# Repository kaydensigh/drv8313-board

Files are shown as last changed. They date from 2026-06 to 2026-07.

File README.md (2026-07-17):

# DRV8313 Board

An open-hardware **3-phase motor driver module** built around the Texas Instruments
[**DRV8313**](https://www.ti.com/lit/ds/symlink/drv8313.pdf) (three half-bridges, 8–60 V).
It drives BLDC/PMSM motors (3-PWM / FOC, e.g. with [SimpleFOC](https://simplefoc.com)),
and — because the three half-bridges and their enables are broken out independently —
also brushed-DC motors, solenoids, and 6-step/trapezoidal loads.

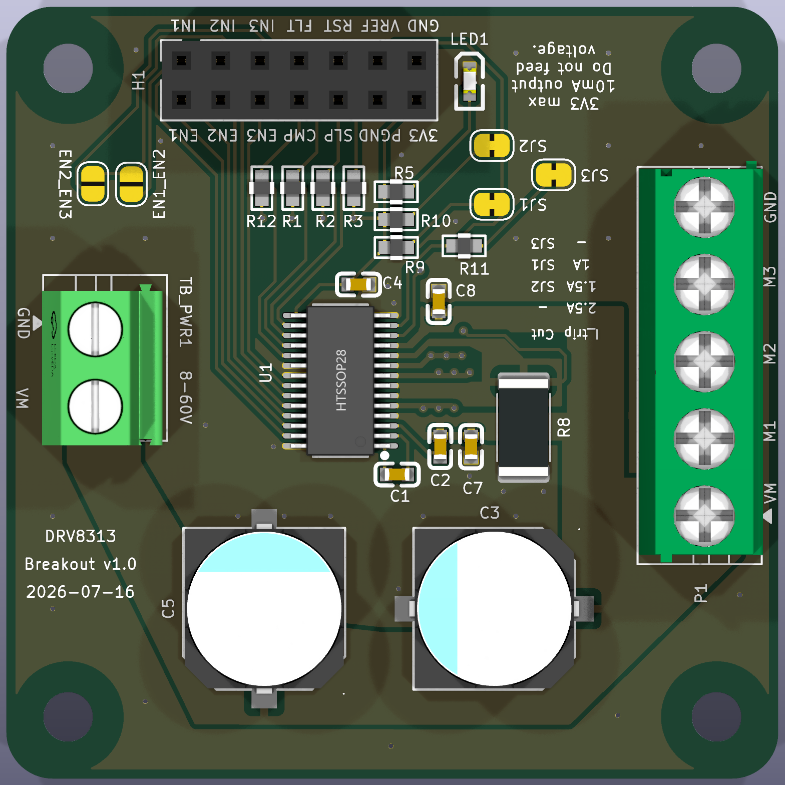
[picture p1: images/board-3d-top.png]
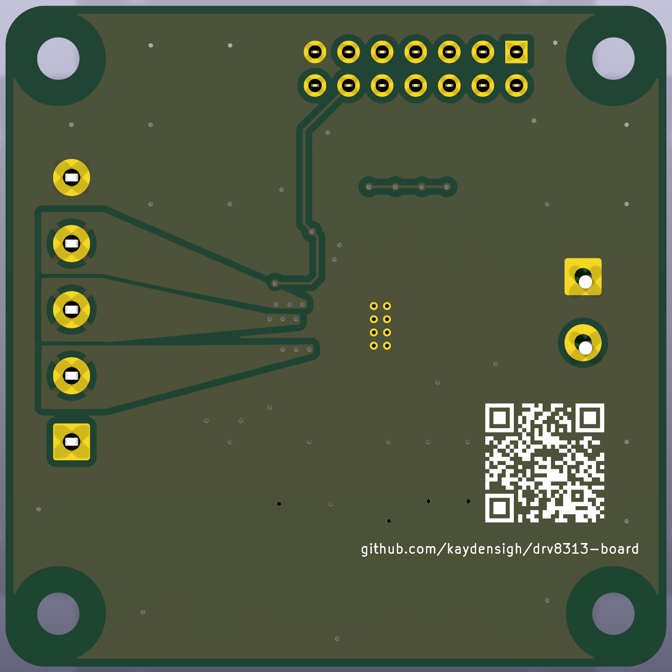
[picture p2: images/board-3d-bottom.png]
 

> Derived from the [SimpleFOCMini](https://github.com/simplefoc/SimpleFOCMini) board
> ([EasyEDA source](https://easyeda.com/the.skuric/simplefocmini)) and re-engineered for
> the DRV8313's full voltage range. It has since diverged substantially from the original
> (higher voltage, larger 4-layer board, on-board current limit, independent half-bridge
> enables), hence the separate project.

## Specifications

| | |
| --- | --- |
| Driver | DRV8313PWPR (HTSSOP-28, exposed thermal pad) |
| Supply voltage | **8–60 V** |
| Continuous current | **~1.5 A / phase** (1 oz copper, Tj ≤ 125 °C; ~2 A with airflow). The datasheet's 2.5 A/phase is a *peak* rating. |
| Logic level | 3.3 V (DRV8313 on-chip `V3P3OUT` regulator; no separate LDO). The `3.3V` header pin is an **output only — max 10 mA**; never drive it from the host. |
| Board | **50 × 50 mm**, 4-layer (Top / GND / GND / Bottom, 1 oz) |
| Control | 3× IN (PWM) + 3× independent EN (solder jumpers gang them for 3-PWM/FOC); nRESET / nSLEEP / nFAULT |
| Current limit | On-board comparator (50 mΩ shunt + jumper-set reference divider); raises `nCOMPO` flag on the header — host acts on it, no automatic shutdown |
| Connectors | 2×7 control header, 5-pos motor/VM terminal block, 2-pos power terminal block |

### Features beyond the original SimpleFOCMini

- **8–60 V** input (vs. 8–24 V) on a 4-layer board with inner ground planes.
- **On-board over-current detection** using the DRV8313's internal comparator (`COMPP`/`COMPN`):
  a 50 mΩ low-side shunt and a 3.3 V reference divider, with three solder jumpers (bridged by
  default) setting the trip point — all bridged ≈ 2.5 A, cut `SJ1` ≈ 1.05 A, cut `SJ2` ≈ 1.5 A,
  cut `SJ3` disables it. The comparator raises the open-drain `nCOMPO` flag on the header; it
  does not shut the bridge down by itself.
- **Independent half-bridge enables** (`EN1`/`EN2`/`EN3`, each brought out on the header) so the
  board can run brushed-DC / solenoid / 6-step loads. Two **solder jumpers on the board**
  (`EN1_EN2`, `EN2_EN3` — open by default) gang the three enables back together for the
  original 3-PWM/FOC drive: bridge both and a single host pin drives all three, with no wiring
  at the header.

## Renders

| Schematic | PCB (top) | PCB (bottom) |
| --- | --- | --- |
|  |  |  |

## Repository layout

| Path | Contents |
| --- | --- |
| [`KiCad/project/`](./KiCad/project/) | KiCad 10 source — schematic, PCB, project, and the `drv8313-board` project library (`.pretty` footprints + `.kicad_sym` symbols) |
| [`manufacturing/`](./manufacturing/) | Fabrication outputs: [`gerbers/`](./manufacturing/gerbers/) (Gerber + Excellon drill), [BOM](./manufacturing/drv8313-board-BOM.csv), [pick-and-place CPL](./manufacturing/drv8313-board-CPL.csv), and a [STEP](./manufacturing/drv8313-board.step) 3D model |
| [`docs/`](./docs/) | [`datasheets/`](./docs/datasheets/) — the DRV8313 datasheet (authoritative part reference) |
| [`tools/`](./tools/) | Headless helper scripts — JLCPCB part search, manufacturing-file regeneration, silk version bump ([`tools/README.md`](./tools/README.md)) |
| [`images/`](./images/) | Renders used above |

The design is maintained **only** in KiCad now; the original Altium / EasyEDA / PDF exports
have been removed. The manufacturing files are regenerated from the KiCad project with
[`tools/build_manufacturing.py`](./tools/build_manufacturing.py) (a `kicad-cli` wrapper).

## Bill of materials

The full BOM (with footprints) is [`manufacturing/drv8313-board-BOM.csv`](./manufacturing/drv8313-board-BOM.csv).
Each MPN below links to its LCSC product page; **Library** is the JLCPCB part class —
**Basic** and **Preferred** are fee-free, **Extended** parts each add a one-time setup fee.

| Designator | Value | Qty | MPN | Unit price | Library |
| --- | --- | --- | --- | --- | --- |
| C1 | 10nF 100V | 1 | [CL10B103KC8NNNC](https://www.lcsc.com/product-detail/multilayer-ceramic-capacitors-mlcc-smd-smt_samsung-electro-mechanics-cl10b103kc8nnnc_C84709.html) | $0.0058 | Extended |
| C2 | 100nF 16V | 1 | [CC0603KRX7R9BB104](https://www.lcsc.com/product-detail/multilayer-ceramic-capacitors-mlcc-smd-smt_yageo-cc0603krx7r9bb104_C14663.html) | $0.0194 | Basic |
| C3,C5 | 47uF 100V | 2 | [RVT2A470M1010](https://www.lcsc.com/product-detail/aluminum-electrolytic-capacitors-smd_honor-elec-rvt2a470m1010_C87862.html) | $0.1206 | Extended |
| C4 | 470nF | 1 | [CL10B474KA8NNNC](https://www.lcsc.com/product-detail/multilayer-ceramic-capacitors-mlcc-smd-smt_samsung-electro-mechanics-cl10b474ka8nnnc_C1623.html) | $0.0254 | Basic |
| C7,C8 | 100nF 100V | 2 | [CL10B104KC8NNNC](https://www.lcsc.com/product-detail/multilayer-ceramic-capacitors-mlcc-smd-smt_samsung-electro-mechanics-cl10b104kc8nnnc_C15725.html) | $0.0297 | Extended |
| H1 | PinHeader 2x7 2.54mm | 1 | [2.54-2\*7P Female](https://www.lcsc.com/product-detail/female-headers_boomele-boom-precision-elec-2-54-2-7p_C38844.html) | $0.1101 | Extended |
| LED1 | Yellow | 1 | [NCD0603Y2](https://www.lcsc.com/product-detail/led-indication-discrete_foshan-nationstar-optoelectronics-ncd0603y2_C89811.html) | $0.0194 | Preferred |
| P1 | TerminalBlock 5P 5.0mm | 1 | [DB126V-5.0-5P-GN-P](https://www.lcsc.com/product-detail/screw-terminal-blocks_dorabo-db126v-5-0-5p-gn-p_C2835160.html) | $0.2395 | Extended |
| R1-R3,R12 | 10kΩ | 4 | [0603WAF1002T5E](https://www.lcsc.com/product-detail/chip-resistor-surface-mount_uni-royal-uniroyal-elec-0603waf1002t5e_C25804.html) | $0.0078 | Basic |
| R5,R11 | 1kΩ | 2 | [0603WAF1001T5E](https://www.lcsc.com/product-detail/chip-resistor-surface-mount_uni-royal-uniroyal-elec-0603waf1001t5e_C21190.html) | $0.0024 | Basic |
| R8 | 50mΩ | 1 | [HoJLR2512-3W-50mR-1%](https://www.lcsc.com/product-detail/current-sense-resistors-shunt-resistors_milliohm-hojlr2512-3w-50mr-1_C2903475.html) | $0.0676 | Extended |
| R9 | 43kΩ | 1 | [0603WAF4302T5E](https://www.lcsc.com/product-detail/chip-resistor-surface-mount_uni-royal-uniroyal-elec-0603waf4302t5e_C23172.html) | $0.0076 | Preferred |
| R10 | 62kΩ | 1 | [0603WAF6202T5E](https://www.lcsc.com/product-detail/chip-resistor-surface-mount_uni-royal-uniroyal-elec-0603waf6202t5e_C23221.html) | $0.0092 | Preferred |
| TB_PWR1 | TerminalBlock 2P 5.0mm | 1 | [DB126V-5.0-2P-GN-P](https://www.lcsc.com/product-detail/screw-terminal-blocks_dorabo-db126v-5-0-2p-gn-p_C395849.html) | $0.0876 | Extended |
| U1 | DRV8313PWPR | 1 | [DRV8313PWPR](https://www.lcsc.com/product-detail/brushless-dc-bldc-motor-driver_texas-instruments-drv8313pwpr_C92482.html) | $1.4973 | Extended |

**Component cost ≈ $2.43/board in volume** (unit prices at JLCPCB's 100-piece tier, 2026-07-17;
U1 dominates). 8 parts are **Extended** (one-time setup fee each); the rest are fee-free.

**A small batch of 10 boards ≈ $55.53 in parts (~$5.55/board)**: $31.53 of components (JLCPCB
per-part assembly minimums + attrition applied) plus 8 × $3 Extended-part setup fees ($24). The
fixed fees amortise over larger runs. Excludes PCB fabrication, assembly labour and shipping.

Regenerate these from live prices with [`tools/gen_readme_bom.py`](./tools/gen_readme_bom.py)
(`--batch N` for a different run size); verify live stock with
[`tools/check_bom.py`](./tools/check_bom.py).

## Ordering

The board is designed to be fabricated and assembled at [JLCPCB](https://jlcpcb.com):

1. Upload `manufacturing/gerbers/` (zipped) for fabrication — 4-layer, 1 oz.
2. Use `manufacturing/drv8313-board-BOM.csv` and `manufacturing/drv8313-board-CPL.csv`
   for assembly. Every line carries an LCSC part number. Most parts are **fee-free** on
   JLCPCB — Basic or Preferred, no per-part setup fee — including the 43 k/62 k divider
   resistors (Preferred). The unavoidable **Extended** parts are the DRV8313 itself, the
   10 nF/100 V, 100 nF/100 V and 47 µF/100 V capacitors, the 50 mΩ current-sense shunt, and
   the three connectors. The connectors — `H1` (2×7 header), `P1` and `TB_PWR1` (5 mm screw terminal
   blocks) — are **through-hole**: order them via JLCPCB's through-hole assembly add-on or
   solder them by hand. Re-verify live stock before ordering — `tools/jlc_search.py` checks
   live stock/price (note: the 10 kΩ Basic resistor occasionally reads out of stock).

> **Status:** functional design — schematic and PCB are complete, fully routed, and both
> **DRC- and ERC-clean (0 violations)**. Not yet fabricated/validated in hardware. Review
> before ordering. Re-verify any time with
> [`tools/check_design.py`](./tools/check_design.py) (DRC + connectivity + ERC) and
> [`tools/check_bom.py`](./tools/check_bom.py) (live JLCPCB part stock).

## License

See [`LICENSE`](./LICENSE). This project inherits from the open-source SimpleFOCMini; please
also credit the original authors.

## Credits

Based on [**SimpleFOCMini**](https://github.com/simplefoc/SimpleFOCMini) by the
[SimpleFOC](https://simplefoc.com) project (Antun Skuric et al.).

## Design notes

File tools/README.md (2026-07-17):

# tools/

Headless helper scripts for the DRV8313 board. They run against the KiCad
project under [`../KiCad/project/`](../KiCad/project/) and need only KiCad 10's
bundled Python / `kicad-cli` — no GUI. On Windows:

```powershell
$PY = "C:\Program Files\KiCad\10.0\bin\python.exe"
& $PY tools\<script>.py ...
```

`jlc_search.py` is stdlib-only (any Python 3); the other two need KiCad's
`pcbnew` / `kicad-cli`, so use the bundled interpreter above.

---

## `jlc_search.py` — pick JLCPCB / LCSC parts

Queries the **live** JLCPCB parts API and ranks matches the way this BOM is
sourced: **fee-free first**, then **cheapest unit price**, in stock only.
JLCPCB charges a per-part setup fee only for plain **Extended** parts — **Basic**
and **Preferred** parts incur no extra charge — so those rank first.

```powershell
& $PY tools\jlc_search.py "10kohm 0603 1%"            # ranked table
& $PY tools\jlc_search.py "100nF 0603 X7R" --fee-free  # Basic OR Preferred only
& $PY tools\jlc_search.py "47uF 100V" --fee-free       # confirm no fee-free option exists
& $PY tools\jlc_search.py C92482                       # look up one part by LCSC id
```

Flags: `--fee-free` / `--basic` / `--preferred` apply a **server-side** library
filter — the reliable way to surface no-fee parts, since a plain keyword search
ranks cheap Extended parts first and buries the Basic/Preferred ones. Also
`--package 0603`, `--attr 1%` (substring in the description), `--qty N`
(unit-price tier, default 50), `--min-stock N`, `--pages N`, `--json`.

> The [yaqwsx/jlcparts](https://yaqwsx.github.io/jlcparts) browser mirrors the
> same JLC catalogue into a static database — handy to browse, heavier to
> script against. This script hits the source API live, so stock/price are
> current and no catalogue download is needed.

## `build_manufacturing.py` — regenerate all fabrication outputs

Rebuilds the JLCPCB fab package **and** the README visuals from the project, so
a design change never leaves stale outputs behind.

```powershell
& $PY tools\build_manufacturing.py            # everything
& $PY tools\build_manufacturing.py --fab      # gerbers / drill / zip / CPL / BOM / STEP only
& $PY tools\build_manufacturing.py --images   # 3D renders + SVGs only
```

Produces, under [`../manufacturing/`](../manufacturing/): `gerbers/` (Protel
extensions) + Excellon drill, `drv8313-board-gerbers.zip` (upload-ready),
`drv8313-board-CPL.csv` (pick-and-place), `drv8313-board-BOM.csv` (grouped, with
MPN + LCSC), `drv8313-board.step`; and under [`../images/`](../images/):
`board-3d-{top,bottom}.png` (straight top-down / bottom-up 3D renders),
`schematic.svg`, and `pcb-{top,bottom}.svg` (2D copper + silk plots on a dark
background — KiCad's SVG export is always transparent, so a background rect is
injected for legibility).

It keeps a **defensive snapshot of `project.kicad_pro`** — a no-op on the current
canonical file (kicad-cli leaves it byte-identical; verified), restored with a
warning only if a future KiCad version re-normalises it. It only *generates*; it
does not run DRC/ERC. Override the toolchain with `$env:KICAD_CLI`.

## `set_silk_version.py` — bump the silkscreen version stamp

```powershell
& $PY tools\set_silk_version.py --show        # current: Breakout v1.0 / 2026-07-16
& $PY tools\set_silk_version.py 2.1           # -> Breakout v2.1
& $PY tools\set_silk_version.py 2.1 --date 2026-09-01   # also stamp a date
& $PY tools\set_silk_version.py 2.1 --date auto         # ... or today
```

Rewrites the `vN.M` token wherever it appears on a silk layer (preserving a
surrounding label like `Breakout `) plus the **ISO `YYYY-MM-DD`** date stamp —
the format this board's silk uses. `--date` takes an ISO date or `auto`
(today), and rejects anything that isn't a real calendar date. Silk **text
only** — copper/geometry untouched; does not edit README/docs version
references. After bumping, regenerate the board images with
`build_manufacturing.py`.

---

## `render_datasheet.py` — render datasheet PDF pages to images

Text extraction loses a datasheet's **figures** — and the reference schematic
you wire from *is* a figure. Render the page, look at the image, and wire from
what the figure shows; never wire from prose text-extraction alone. (The
DRV8313 datasheet's §8.2.2.2.1 prose contradicts its own Figure 12 on the
comparator pins — following the text wires COMPP/COMPN backwards.)

```powershell
& $PY tools\render_datasheet.py docs\datasheets\drv8313.pdf --toc   # find the right pages
& $PY tools\render_datasheet.py docs\datasheets\drv8313.pdf 12      # §7.3.4 comparator figure
& $PY tools\render_datasheet.py some.pdf 13-15,23 --dpi 200 --out-dir _scratch_ds
```

Uses PyMuPDF (`fitz`), installed in KiCad's bundled Python. PNGs land in
`%TEMP%\datasheet-render\<stem>\` by default; paths are printed. Page numbers
are 1-based PDF pages. `--toc` prints the bookmark tree so you can jump
straight to "Application and Implementation" or a pin-function table.

## `render_sch.py` — render the schematic for visual inspection

ERC and the netlist prove the schematic is *correct*; only looking at a render
proves it is *readable*. Render + inspect after every placement/label edit —
the visual analogue of running DRC after every copper edit.

```powershell
& $PY tools\render_sch.py                          # whole sheet -> %TEMP%\kicad-render\
& $PY tools\render_sch.py --density 300            # zoom to read labels
& $PY tools\render_sch.py --crop 800x600+200+150   # pixel crop of one region
```

Needs `kicad-cli` + ImageMagick `magick` (both installed); any Python 3 works.

## `sch_lint.py` — schematic readability lint (numeric oracle)

Scores the visual defects blind editing introduces: overlapping value/ref
text, text through symbol bodies or across wires, wire crossings, stacked
symbols, off-grid endpoints. Iterate edits against this score the way copper
edits iterate against DRC, then confirm with `render_sch.py`. Geometry is
heuristic (text boxes estimated from character counts, bodies from pin
extents) — findings are pointers to check in a render, and the total is a
score to drive down, not ground truth.

```powershell
& $PY tools\sch_lint.py                    # report + total
& $PY tools\sch_lint.py --verbose --json   # every finding, machine-readable
& $PY tools\sch_lint.py --fail-over 10     # CI gate on the issue count
```

Needs kicad-skip, so run with KiCad's bundled Python. Informational findings
(e.g. a power symbol placed directly on a component pin — electrically fine
but the part looks unwired) are reported but not counted.

---

## `check_design.py` — verify DRC / connectivity / ERC

Runs the checks the board is validated against and prints a PASS/FAIL summary;
**exits nonzero if any hard check fails** (drop into CI or a pre-commit hook).

```powershell
& $PY tools\check_design.py
```

| Check | Tool | Gate |
| --- | --- | --- |
| DRC (error severity) | `kicad-cli pcb drc --severity-error --refill-zones` | **hard** — must be 0 (authoritative: incl. unconnected, clearance, shorts) |
| Connectivity (all nets) | KiCadRoutingTools `check_connected.py` | advisory cross-check |
| Clearance / shorts | KiCadRoutingTools `check_drc.py` | advisory cross-check |
| ERC | `kicad-cli sch erc` | tripwire — flagged if `!= 0` |

kicad-cli's error-severity DRC is the authoritative connectivity/clearance/short
gate (its ratsnest understands zone fills + through-pad + off-anchor pad entries).
The two KRT checks are **advisory** only — their endpoint-graph model emits false
positives on perfectly-connected manual routing (a track ending inside a pad but
not at its anchor, or tracks meeting *through* a large pad), so they print but
never fail the build. The ERC baseline (0 = fully clean) and the DRC
*warning*-severity items are EasyEDA-import cosmetic artifacts (documented in
CLAUDE.md), so ERC is a **regression tripwire**, not a gate. Keeps a defensive
`project.kicad_pro` snapshot (a no-op today — kicad-cli leaves the canonical file
untouched).
Needs [KiCadRoutingTools](https://github.com/drandyhaas/KiCadRoutingTools) at
`../KiCadRoutingTools` for the connectivity/clearance checks (override with
`$env:KRT_DIR` / `$env:KRT_PYTHON`); if absent, those two are skipped and the
gate falls back to DRC + ERC.

## `check_bom.py` — verify BOM stock + fee status (live)

Looks up every LCSC part in `manufacturing/drv8313-board-BOM.csv` on JLCPCB and
reports stock, Basic/Preferred/Extended (fee status) and price; **flags
out-of-stock / discontinued parts and exits nonzero** if any part is out of
stock — the exact failures that bit this BOM (LED1 went out of stock; the 10 kΩ
Basic part periodically reads 0). Run it before ordering.

```powershell
& $PY tools\check_bom.py                  # fails on any 0-stock part
& $PY tools\check_bom.py --min-stock 100  # also fail on low stock
& $PY tools\check_bom.py --bom other.csv
```

Reuses `jlc_search.py`. Also tallies the unique Extended parts (= one JLCPCB
setup fee each). *(As of this writing it reports the 10 kΩ `C25804` out of stock
— a transient JLC condition on its most-used Basic resistor; re-run before
ordering.)*

## `gen_readme_bom.py` — Markdown BOM table for the README

Emits the README's Bill-of-materials table from the BOM CSV plus **live** JLCPCB
prices: `Designator | Value | Qty | MPN | Unit price | Library`, each MPN linked
to its LCSC page, followed by an estimated per-board component-cost total.

```powershell
& $PY tools\gen_readme_bom.py                  # paste output into README.md
& $PY tools\gen_readme_bom.py --price-qty 10   # quote a different price tier
```

Prices are live, so the table is a dated snapshot — re-run to refresh. Reuses
`jlc_search.py`.

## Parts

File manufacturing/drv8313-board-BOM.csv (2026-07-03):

Designator | Value | Footprint | Qty | MPN | LCSC
C1 | 10nF 100V | drv8313-board:C0603 | 1 | CL10B103KC8NNNC | C84709
C2 | 100nF 16V | drv8313-board:C0603 | 1 | CC0603KRX7R9BB104 | C14663
C3,C5 | 47uF 100V | drv8313-board:CAP-SMD_BD10.0-L10.3-W10.3-FD-LS11.0 | 2 | RVT2A470M1010 | C87862
C4 | 470nF | drv8313-board:C0603 | 1 | CL10B474KA8NNNC | C1623
C7,C8 | 100nF 100V | drv8313-board:C0603 | 2 | CL10B104KC8NNNC | C15725
H1 | PinHeader 2x7 2.54mm | Connector_PinSocket_2.54mm:PinSocket_2x07_P2.54mm_Vertical | 1 | 2.54-2*7P Female | C38844
LED1 | Yellow | drv8313-board:LED0603-R-RD | 1 | NCD0603Y2 | C89811
P1 | TerminalBlock 5P 5.0mm | TerminalBlock:TerminalBlock_MaiXu_MX126-5.0-05P_1x05_P5.00mm | 1 | DB126V-5.0-5P-GN-P | C2835160
R1-R3,R12 | 10kΩ | drv8313-board:R0603 | 4 | 0603WAF1002T5E | C25804
R5,R11 | 1kΩ | drv8313-board:R0603 | 2 | 0603WAF1001T5E | C21190
R8 | 50mΩ | Resistor_SMD:R_2512_6332Metric | 1 | HoJLR2512-3W-50mR-1% | C2903475
R9 | 43kΩ | drv8313-board:R0603 | 1 | 0603WAF4302T5E | C23172
R10 | 62kΩ | drv8313-board:R0603 | 1 | 0603WAF6202T5E | C23221
TB_PWR1 | TerminalBlock 2P 5.0mm | TerminalBlock:TerminalBlock_MaiXu_MX126-5.0-02P_1x02_P5.00mm | 1 | DB126V-5.0-2P-GN-P | C395849
U1 | DRV8313PWPR | drv8313-board:HTSSOP-28_L9.8-W4.5-P0.65-LS6.6-BL-EP | 1 | DRV8313PWPR | C92482

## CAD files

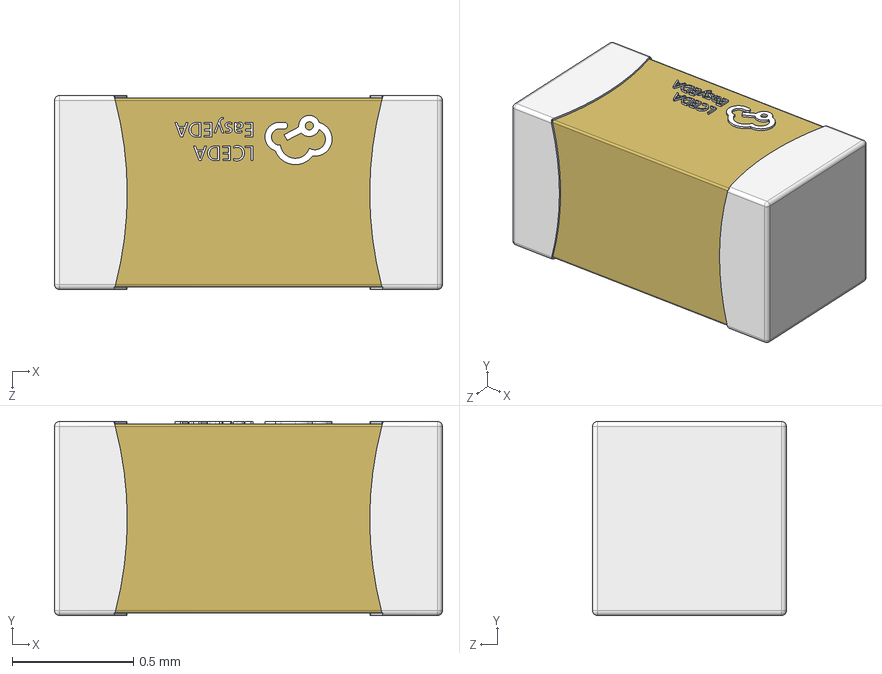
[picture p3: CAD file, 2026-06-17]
KiCad/project/EASYEDA_MODELS/C0603_L1.6-W0.8-H0.8.step
1.60 x 0.8 x 0.8 mm

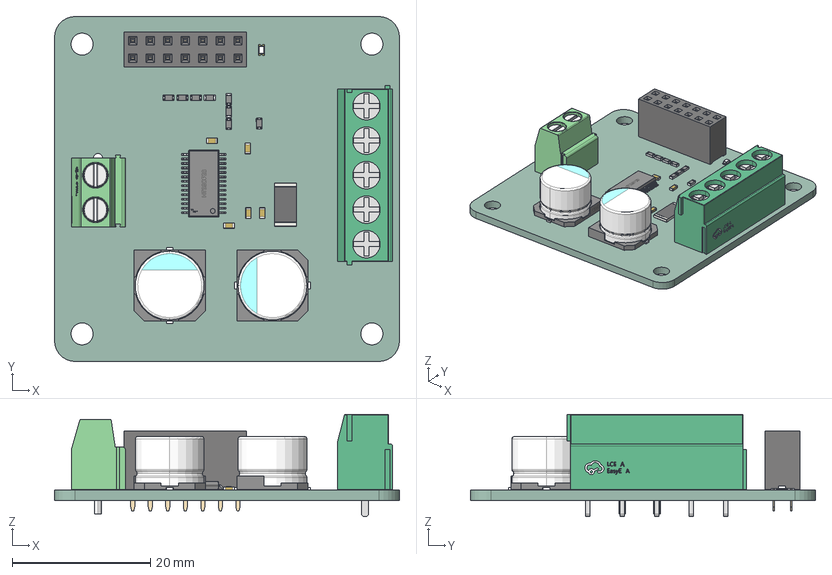
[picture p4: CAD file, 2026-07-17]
manufacturing/drv8313-board.step
50.0 x 50.0 x 14.8 mm
R0603 x 8
C0603_L1.6-W0.8-H0.8 x 5
CONN-TH_DB5.00-LI-2P-126
CONN-TH_5P-P5.00-L8.0-W25.0
HTSSOP-28_L9.7-W4.4-H1.2-LS6.4-P0.65
R_2512_6332Metric
PinSocket_2x07_P2.54mm_Vertical
CAP-SMD_BD10.0-L10.3-W10.3-FD-LS11.0 x 2
LED0603-RD-YELLOW
project_PCB

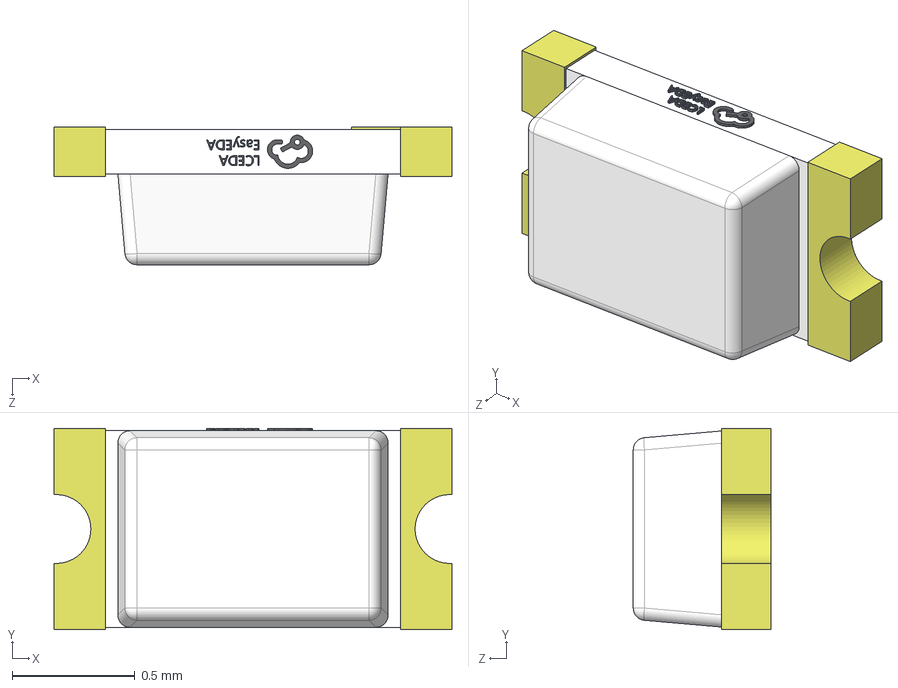
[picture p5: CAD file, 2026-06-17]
KiCad/project/EASYEDA_MODELS/LED0603-RD-YELLOW.step
1.62 x 0.82 x 0.56 mm

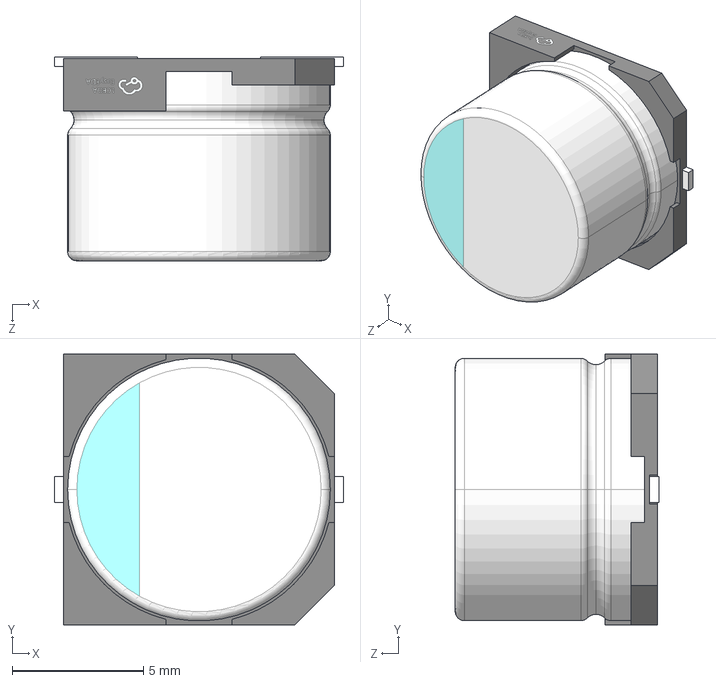
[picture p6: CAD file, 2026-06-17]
KiCad/project/EASYEDA_MODELS/CAP-SMD_BD10.0-L10.3-W10.3-FD-LS11.0.step
11.0 x 10.3 x 7.75 mm

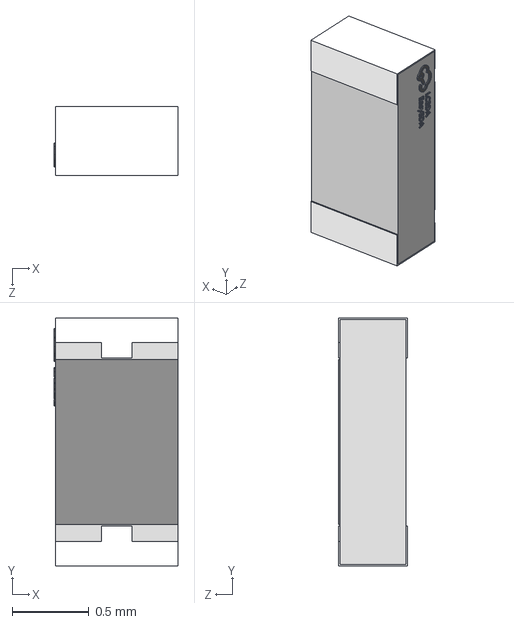
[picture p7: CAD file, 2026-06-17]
KiCad/project/EASYEDA_MODELS/R0603.step
0.81 x 1.62 x 0.45 mm

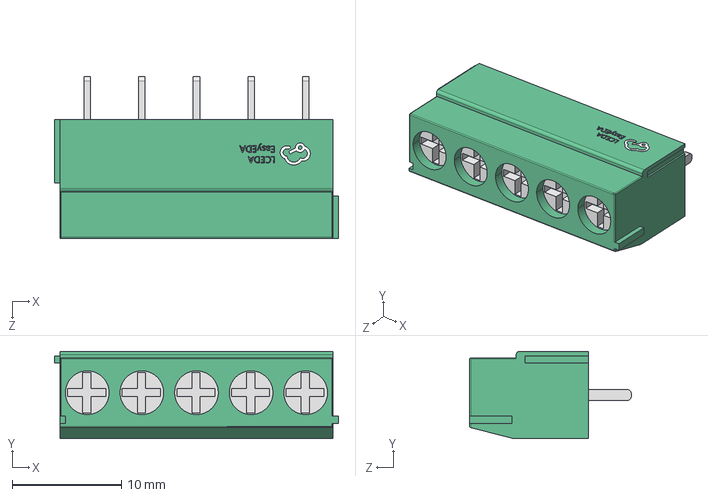
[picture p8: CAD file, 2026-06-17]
KiCad/project/EASYEDA_MODELS/CONN-TH_5P-P5.00-L8.0-W25.0.step
26.0 x 8.00 x 14.8 mm

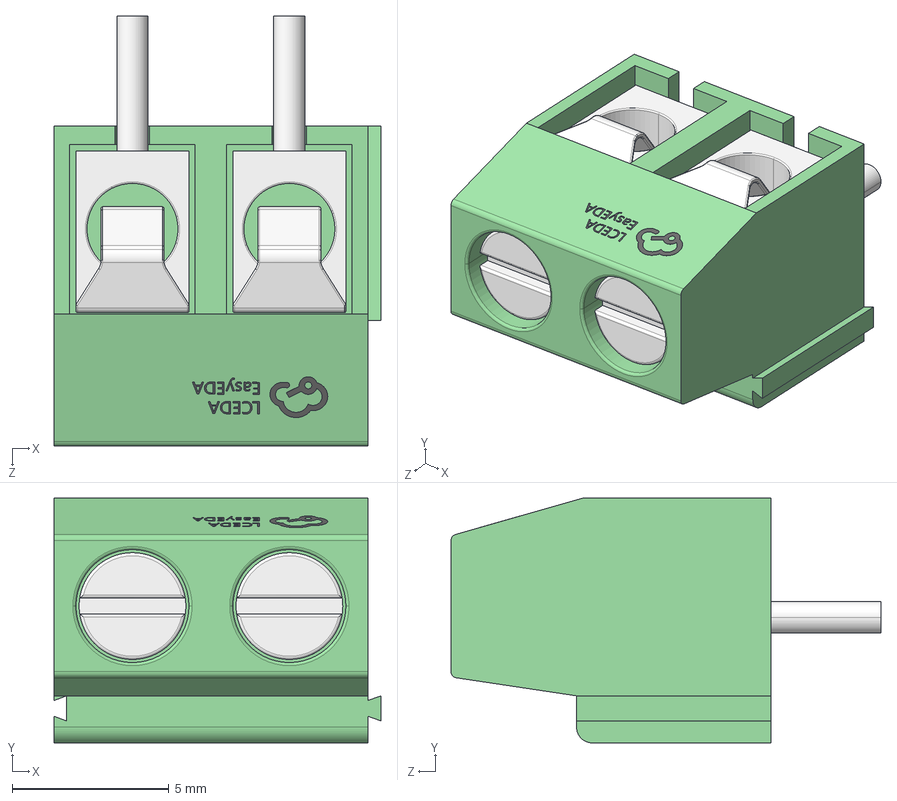
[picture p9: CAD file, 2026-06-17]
KiCad/project/EASYEDA_MODELS/CONN-TH_DB5.00-LI-2P-126.step
10.4 x 7.80 x 13.7 mm

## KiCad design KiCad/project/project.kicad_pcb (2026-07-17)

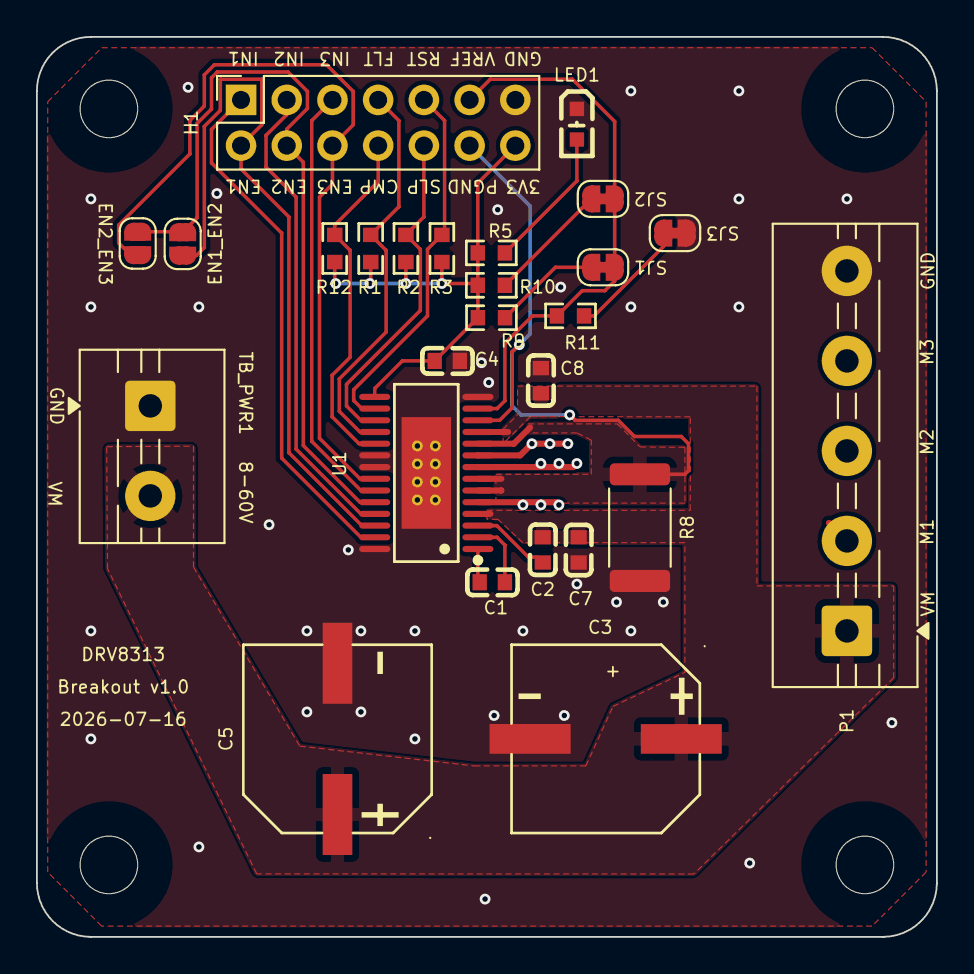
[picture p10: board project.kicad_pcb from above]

Board: 4 copper layers, 50.0 x 50.0 mm, 30 parts (0 on the bottom side), 25 nets.

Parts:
C1: 10nF 100V; C0603
C2: 100nF 16V; C0603
C3, C5: 47uF 100V; CAP-SMD_BD10.0-L10.3-W10.3-FD-LS11.0
C4: 470nF; C0603
C7, C8: 100nF 100V; C0603
EN1_EN2, EN2_EN3: SolderJumper_2_Open; SolderJumper-2_P1.3mm_Open_RoundedPad1.0x1.5mm
H1: PinHeader 2x7 2.54mm; PinSocket_2x07_P2.54mm_Vertical
LED1: Yellow; LED0603-R-RD
MH1, MH2, MH3, MH4: MountingHole_3.2mm_M3
P1: TerminalBlock 5P 5.0mm; TerminalBlock_MaiXu_MX126-5.0-05P_1x05_P5.00mm
R1, R2, R3, R12: 10kΩ; R0603
R5, R11: 1kΩ; R0603
R8: 50mΩ; R_2512_6332Metric
R9: 43kΩ; R0603
R10: 62kΩ; R0603
SJ1, SJ2, SJ3: JMP; SolderJumper-2_P1.3mm_Bridged_RoundedPad1.0x1.5mm
TB_PWR1: TerminalBlock 2P 5.0mm; TerminalBlock_MaiXu_MX126-5.0-02P_1x02_P5.00mm
U1: DRV8313PWPR; HTSSOP-28_L9.8-W4.5-P0.65-LS6.6-BL-EP

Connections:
3.3V: C4.2, H1.14, R1.1, R2.1, R3.1, R5.1, R9.1, R10.1, R12.2, U1.15 (V3P3OUT)
EN1: EN1_EN2.1 (A), H1.2, U1.26 (EN1)
EN2: EN1_EN2.2 (B), EN2_EN3.1 (A), H1.4, U1.24 (EN2)
EN3: EN2_EN3.2 (B), H1.6, U1.22 (EN3)
GND: C3.2, C4.1, C5.2, C7.1, C8.1, H1.13, LED1.2 (C), P1.5, R8.2, SJ3.2 (B), TB_PWR1.1, U1.14 (GND), U1.20 (GND), U1.21 (NC), U1.28 (GND), U1.29 (EP)
IN1: H1.1, U1.27 (IN1)
IN2: H1.3, U1.25 (IN2)
IN3: H1.5, U1.23 (IN3)
M1: P1.2, U1.5 (OUT1)
M2: P1.3, U1.8 (OUT2)
M3: P1.4, U1.9 (OUT3)
unnamed: LED1.1 (A), R5.2
unnamed: R9.2, SJ1.1 (A)
unnamed: R10.2, SJ2.1 (A)
unnamed: R11.2, SJ3.1 (A)
unnamed: C1.2, U1.1 (CP1)
unnamed: C1.1, U1.2 (CP2)
unnamed: C2.2, U1.3 (VCP)
PGND: H1.12, R8.1, U1.6 (PGND1), U1.7 (PGND2), U1.10 (PGND3), U1.12 (COMPP)
VCC: C2.1, C3.1, C5.1, C7.2, C8.2, P1.1, TB_PWR1.2, U1.4 (VM), U1.11 (VM)
VREF: H1.11, R11.1, SJ1.2 (B), SJ2.2 (B), U1.13 (COMPN)
nCOMPO: H1.8, R12.1, U1.19 (COMPO#)
nFlt: H1.7, R1.2, U1.18 (FAULT#)
nRes: H1.9, R3.2, U1.16 (RESET#)
nSlp: H1.10, R2.2, U1.17 (SLEEP#)

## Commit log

2026-06-16 Add KiCad 10 project converted from EasyEDA source
    Imported from the EasyEDA Std design files via KiCad's importer.
    All 13 components, board outline, routing, vias, and GND/VCC copper
    pours came across. Known import artifacts (clearance/silk/parity noise,
    schematic pin-type and library associations) to be cleaned up next.
    [project.kicad_pcb, project.kicad_sch]
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2026-06-16 Configure project for 60V redesign: 4-layer stackup + Power net class
    Project-setup pass (board config only; no copper re-routed yet):
    - PCB set to 4 copper layers via pcbnew: F.Cu (TopLayer), In1.Cu (GND1),
    In2.Cu (GND2), B.Cu (BottomLayer), 1.6mm. Inner layers named to encode
    the Top/GND/GND/Bottom intent; pour GND zones on them during layout.
    - Add a Power net class (0.8mm track ~= 2A headroom on 1oz, 0.3mm clearance
    for 60V, 0.8/0.4mm vias) and assign VCC + phase outputs U1_5/U1_8/U1_9
    via netclass_patterns. Default left at 0.2mm so HTSSOP escape stays
    routable; 60V clearance is enforced per-net on the power nets.
    - Record setup-pass facts and gotchas in CLAUDE.md.
    Note: edit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
    [project.kicad_pcb]
2026-06-16 Schematic: mark C3/C1 for 60V; add redesign BOM worklist
    - C3 Value -> '100uF 100V', C1 Value -> '100nF 100V' (the two hard-fail
    caps at 60V: VM bulk and charge-pump flying cap). ERC unchanged at 87.
    - Left MPN/Supplier-Part fields untouched: the EasyEDA import shares those
    strings across symbols (C1/C2 both carry CL10B104KB8NNNC), so a global
    blank would corrupt siblings. Re-select MPNs per-symbol during rework.
    - Add docs/redesign-bom.md: per-reference part-selection worklist with
    status flags. Concrete call: P1 -> TB002-500-03BE (3-pos sibling of
    TB_PWR1's TB002-500-02BE). Open decisions: C1 value (10nF vs 100nF),
    R5 value (1k vs 4.7k), LED1 re-site to 3.3V.
    - README + CLAUDE.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
    [project.kicad_sch]
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2026-06-16 Apply cap decisions + re-site LED1 to 3.3V in schematic
    - C1 Value -> '10nF 100V' (Samsung C84709, TI datasheet value)
    - C3 Value -> '47uF 100V'; bulk is now 2x 47uF/100V parallel (Honor
    C87862) ~= 94uF at full 100V margin (single extended-part fee). C5
    (the parallel twin) to be added during rework.
    - LED1 re-sited to the 3.3V rail: swapped power symbol #PWR01 on the R5
    branch from VCC to 3.3V. Verified by netlist export: R5.1 now on net
    3.3V; VCC still carries U1.4/U1.11 (VM). ERC unchanged at 87.
    - R5 kept at 1kOhm (~1.3mA indicator on 3.3V).
    - redesign-bom.md + CLAUDE.md updated with decisions and remaining work
    (add C5, set per-symbol MPNs, P1 -> TB002-500-03BE footprint).
    Co-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
    [project.kicad_sch]
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2026-06-16 PCB: net U1 EP thermal vias to GND + add inner GND planes
    - U1's footprint already had an 8-pad PTH thermal-via array under the EP
    but assigned <no net> (floating). Netted all 8 to GND so the exposed
    pad conducts to the ground planes. (Explains the earlier 'zero vias'
    finding: they existed but were unconnected.)
    - Added inner GND planes on In1.Cu/In2.Cu (duplicated from the B.Cu GND
    zone), each filling ~365 mm^2, for 4-layer thermal spreading.
    - DRC: 202 violations, 0 unconnected, 0 shorting_items. Remaining are
    pre-existing import artifacts (silk/text ~159, clearance 18 from the
    60V Power-class on old narrow traces, padstack 14).
    Remaining PCB work (re-layout): widen VM/phase t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
    [project.kicad_pcb]
2026-06-16 Set all text to default font (remove named font faces)
    Removed hard-coded (face ...) overrides from the EasyEDA import: 75 from
    the schematic (Arial, Times New Roman) and 5 from the PCB
    (NotoSerifCJKsc-Medium). The CJK face was uninstalled and triggered a
    missing-font dialog that stalled headless kicad-cli/pcbnew runs. All text
    now uses KiCad's default font. ERC 92 unchanged; DRC 205 (0 unconnected).
    [project.kicad_pcb, project.kicad_sch]
2026-06-16 PCB: add C5 footprint, widen VM trace to 0.8mm
    - Added C5 (clone of C3, netted VCC/GND), parked below the board outline
    pending placement (shows as 2 ratsnest until routed).
    - Widened the VM/VCC trace 0.254 -> 0.8mm (Power-class). No shorts.
    - Phase traces left at 0.5mm: widening to 0.8mm shorts U1_8<->U1_9 at the
    0.65mm-pitch HTSSOP escape (they must neck at the IC, a routing task).
    0.5mm carries 1.5A.
    DRC: 0 shorting_items, 2 unconnected (C5's pads). Remaining are
    pre-existing import artifacts. Footprint resizes + P1 terminal block +
    routing belong to the re-layout (they need the larger board).
    [project.kicad_pcb]
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2026-06-17 PCB: round corners, add M3 corner holes + missing TB_PWR1 footprint
    Continuing the 40x40 mm re-layout (step 1):
    - Edge.Cuts: 3 mm rounded corners (4 segments + 4 fillet arcs).
    - Add MH1-MH4 (MountingHole_3.2mm_M3, NPTH) at the corners, symmetric
    32x32 mm pattern (4 mm inset). MH1 overlaps H1 until H1 is moved.
    - Add TB_PWR1 footprint (was in the schematic but the import never laid
    it out): TerminalBlock_MaiXu_MX126-5.0-02P, pad1->GND, pad2->VCC,
    parked off-board pending placement.
    - Re-pour zones after the edge change (clears stale-fill edge flags).
    DRC: 228 violations, 0 shorting_items, 4 unconnected (C5 + TB_PWR1).
    The 7 Pad_gge* orphans (old 2 mm GND mounting holes + original power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
    [project.kicad_pcb]
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2026-06-17 PCB: place_optimize polish of macro placement
    KiCadRoutingTools place_optimize (connectors/U1/holes locked): airwire
    194.9->179.9mm, crossings 39->19, 10 small parts nudged. Bulk cans manually
    reset clear of MH4 afterward. 0 courtyard overlaps. Writer verified to
    preserve the 4-layer stackup (GND1/GND2 inner names intact), 19 footprints,
    20 nets.
    [project.kicad_pcb]
2026-06-17 PCB: tool routing pass - signals on F/B.Cu + GND inner planes
    route.py (F.Cu/B.Cu, 0.6mm power nets, neck-down): 17/17 single-ended +
    15/17 multipoint routed. route_planes: solid GND planes on In1.Cu/In2.Cu,
    24/24 GND pads stitched (10 new vias), 0.96mOhm / 13A. Zones filled.
    DRC: 0 clearance, 0 shorts, 4 unconnected.
    Pending hand-finish (HTSSOP 0.65mm escape, as predicted): EN pins 22/24,
    VCC(VM) pins 4/11 + C2 - VCC better solved as a pour. Remaining DRC is
    cosmetic silk (149) + the pre-existing U1 EP padstack artifact (10).
    [project.kicad_pcb]
2026-06-17 PCB: routing pass 2 - R5 sync fix, full signal/phase route, GND planes
    - Fixed stale net: R5.1 VCC->3.3V (schematic has LED on V3P3OUT; PCB was
    never synced after the LED-resiting edit). Verified via full PCB<->sch
    connectivity diff - only other mismatch is U1 pin28 GND (PCB ties it,
    schematic floats it; recommend tying in schematic).
    - route.py: all signals + all 3 phase outputs routed (F.Cu/B.Cu, 0.6mm
    power nets, neck-down). VCC routed first to claim its escape corridor.
    - route_planes: GND planes In1/In2, 24/24 pads stitched. Zones filled.
    - DRC: 0 shorts, 0 clearance. 3 unconnected: U1 VM pin 11 + two short
    escape stubs at the 0.65mm HTSSOP power row (fine-pitch escape, for GU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
    [project.kicad_pcb]
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2026-06-17 PCB: hand-route both VM pins (4 & 11) + silk to 60V rev
    Connected U1 VM pins 4 and 11 to the VCC rail with B.Cu via-jogs threaded
    clear of the phase escapes (U1_5/U1_9) and the VCP trace (U1_3 kinks right
    at y114.3, so pin 4 drops above it). VCC now FULLY CONNECTED; 0 shorts,
    0 clearance. Silk: 8-35V -> 8-60V, v1.1 -> v2.0.
    Remaining: 1 EN ratsnest near-miss from the autoroute (check_connected
    counts EN fully connected; KiCad flags a hairline gap) - trivial GUI snap.
    [project.kicad_pcb]
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2026-06-17 Schematic: brushed/solenoid + current-limit redesign (comparator, P1 5-pos, H1 2x7 EN breakout)
    Done headless via kicad-skip; every new/changed net netlist-verified (kicad-cli).
    Comparator current-sense network (TI DRV8313 Fig.12):
    - PGND1/2/3 + COMPP split off GND onto a single shunt R8 (50mohm) -> GND.
    - COMPN reference: divider R9(43k)/R10(62k)/R11(1k) with solder jumpers SJ1/SJ2
    (default 2.5A trip; cut SJ1->1.5A; cut SJ2->disabled) + filter cap C6 (0.47uF).
    - nCOMPO pull-up R12 (10k) to 3V3.
    P1 -> 5-pos terminal block [GND M1 M2 M3 VM] (lib-symbol extended to 5 pins);
    M1/M2/M3 = OUT1/OUT2/OUT3, VM enables sensed low-side loads.
    H1 -> 2x7: EN1/EN2/EN3 broken out, each via its own ser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
    [project.kicad_sch]
2026-06-17 PCB: sync to redesigned schematic (footprints + full re-net)
    Clear all routing (304 tracks/vias), swap H1->2x7 PinSocket and
    P1->5-pos MaiXu MX126-5.0 terminal block, add the 10 new parts
    (R6/R7/R9/R10/R11/R12 R0603, C6 C0603, R8 2512 shunt, SJ1/SJ2 solder
    jumpers), and re-net every pad from the verified schematic netlist.
    Board connectivity now matches the schematic exactly: 92 named pads =
    92 schematic nodes, 0 mismatches. New parts parked off-board pending
    placement; routing/zones to follow.
    Note for pcbnew scripting: delete tracks/footprints with RemoveNative(),
    not Remove() -- Remove() transfers SWIG ownership and corrupts the board
    so later footprint access segfaults. FOOTPRINT.Dupli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
    [project.kicad_pcb]
2026-06-17 PCB: enlarge to 40x45mm and re-place all parts
    Grow Edge.Cuts to 40x45 (x[134,174] y[88,133], 3mm rounded corners) so
    the 5-pos motor terminal block fits the right edge with clearance to the
    corner M3 holes; move MH1-4 to the new corners (4mm inset, pads no-net).
    Placement: TB_PWR1 (power-in) left edge, P1 (5-pos motor-out) right edge,
    H1 (2x7 control) across the top facing U1's logic row, U1 centered. New
    current-sense cluster placed by function: R8 shunt directly below U1's
    PGND pins, comparator divider (R9/R10/R11/SJ1/SJ2/C6) by pin 13/14, EN
    series resistors (R4/R6/R7) and logic pulls between H1 and U1.
    Connectors centered by pad-bbox (their footprint origin is pin 1, not
    center). plac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
    [project.kicad_pcb]
2026-06-17 PCB: autoroute bulk nets clean (M1/M2/M3, PGND, all signals, GND planes)
    Place_optimize-based clear-band placement routes cleanly for the phases,
    PGND island (to the R8 shunt), all logic/control signals, and the two
    inner GND planes (22/22 GND pads stitched). DRC: 0 shorts, 0 crossings.
    Left unrouted for hand-routing (15 connections across 6 nets): VCC (incl.
    the interleaved VM pins 4/11), the CP charge-pump pair, and the comparator
    divider nets VREF/XN/YN. The autorouter cannot escape the interleaved
    VM/PGND power-row pins without shorting PGND -- same dense HTSSOP spot the
    prior pass hand-routed. Fine-pitch escape needs grid 0.05 / clearance 0.15.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
    [project.kicad_pcb]
2026-06-17 PCB: complete routing (all 92 connections), relax via rules for fine pitch
    Hand-routed the last interleaved VM pin (U1.11 VCC) via a B.Cu jog under
    the M1/M2 escapes onto the VCC bus; co-routing VCC+PGND together let the
    router separate the interleaved VM/PGND power-row escapes cleanly. VREF
    (incl. the boxed comparator pin U1.13), CP charge-pump, XN/YN all routed.
    check_connected: ALL NETS FULLY CONNECTED. kicad-cli DRC: 0 unconnected.
    Relaxed via rules to min via 0.4 / drill 0.25 / annular 0.075 (JLC-advanced,
    deliberate fine-pitch choice for the 0.65mm HTSSOP escape) -> clears 36
    via/drill/annular violations.
    Remaining DRC (non-cosmetic): 3 shorting_items + ~13 clearance, ALL in the
    cram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
    [project.kicad_pcb]
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2026-06-17 PCB: clear the 3 comparator-divider shorts (re-place + re-route)
    The divider/solder-jumper cluster (R9/R10/R11/SJ1/SJ2/C6) was the last
    electrical issue: 3 shorting_items where VREF/XN/YN tracks grazed the
    stacked SolderJumper pads (the cluster was too cramped to route).
    Re-laid it as a compact 3-col x 2-row grid of vertical parts, with both
    fat SolderJumpers in the safe middle column (clear of the R8 shunt on the
    left and the MH3 mounting-hole courtyard on the right), then hand-routed:
    VREF on an F.Cu spine in the row gap (y128), the R9<->R10 3.3V tie on B.Cu
    (the one layer change, dodging R10's stacked pads), GND pads dropped
    straight to the inner GND plane via plane vias, and XN/YN as sh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
    [project.kicad_pcb]
2026-06-17 PCB: clear the U1 HTSSOP fine-pitch power-row clearance violations
    The 0.65mm-pitch power row (pins 5-14) had 6 clearance violations from the
    escape routing. All are now cleared by surgical re-routing (no rule
    relaxation, no net changes):
    - VCC(pin11,VM/60V) vs PGND(pins10/12): the 0.6mm PGND bus ran directly
    under pin11, squeezing the VCC via to 0.10-0.15mm. Narrowed that one
    under-pin11 bus segment to 0.3mm -> ~0.30mm clearance. This was the only
    60V-relevant one; note the package itself fixes VM-PGND at 0.307mm pad
    pitch, so the escape now matches the chip's own spacing.
    - PGND pad-entry stubs at pins 10/12 were 0.6mm wide and overhung toward
    pins 9/11 (0.1785mm). Narrowed to 0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
    [project.kicad_pcb]
2026-06-17 PCB: clear the last C3/R4 overlap (move R4 up, re-route EN1/EN1H)
    The bulk cap C3's 9.4mm courtyard / 3.5mm-wide GND pad collided with the
    leftmost EN resistor R4 (1 courtyard_overlap + 1 clearance 0.148mm). C3 is
    boxed (IN1 routing below-left, board edge left), and the EN row is packed
    at 2mm pitch against R12, so neither could shift toward the other.
    Moved R4 up 1.6mm (146,100 -> 146,98.4) so its courtyard clears C3's
    Y-band entirely, then re-routed its two simple 2-point nets EN1 (U1.26<->R4.2)
    and EN1H (H1.4<->R4.1).
    Result: 0 error-severity DRC items (was 2), 0 shorts, 0 unconnected, all 92
    nets connected, net parity unchanged. The board is now electrically clean;
    the 249 remaining DR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
    [project.kicad_pcb]
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2026-06-17 Silk: full cleanup pass — 249 -> 6 cosmetic DRC warnings
    Headless pcbnew. Electrical content untouched (97 pads, 0 net mismatches
    vs prior; 0 unconnected). Silk/text only + one real assembly fix.
    - Hid all redundant silk value fields (kept refs); hid the 4 mounting-hole
    refs (2 were clipping the edge).
    - Deleted 37 stale connector pin-labels left over from the 26mm/2x5-header
    layout (they floated over the wrong parts post-relayout) and regenerated
    correct ones from the netlist: H1 2x7 (GND/3V3/IN1/EN1/IN2/EN2/IN3/EN3/
    RST/SLP/FLT/CMP/PGND/VREF), P1 motor (VM/M3/M2/M1/GND), TB_PWR1 (+/-).
    - FIXED A REAL DEFECT: all 11 R0603 resistors had solder_paste_margin
    = -100mm (EasyEDA impo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
    [project.kicad_pcb]
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2026-06-17 Footprints: back-annotate + library re-link (footprint_symbol_mismatch 29 -> 0)
    Schematic Footprint fields were empty (footprints lived only in the PCB),
    producing 29 footprint_symbol_mismatch parity items. Cleared all 29 headless
    (pcbnew + kicad-skip); 0 unconnected, 0 error-severity DRC, 97 pads stable.
    - 25x empty Footprint field, 2x stale PCB value text (C1 -> 10nF 100V,
    C3 -> 47uF 100V; PCB still read the v1.1 values), 2x SJ1/SJ2 BOM attr
    (excluded from BOM to match the SolderJumper footprint).
    - Bare-name back-annotation alone just moves the problem to ERC (+25
    footprint_link_issues), since the embedded EasyEDA footprints have no
    library home. Fixed by giving them real lib:nam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
    [project.kicad_pcb, project.kicad_sch]
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2026-06-17 PCB: re-place C3/C5 to the Ø10mm footprint (50x45 board); fixes part/footprint mismatch
    C3/C5's BOM part C87862 (RVT2A470M1010, 47uF/100V) is a Ø10mm can but the
    board had the Ø6.3mm footprint (surfaced by easyeda2kicad). Swapped to
    CAP-SMD_BD10.0 and re-laid-out, headless. Electrically clean: 0 error-severity
    DRC, 0 unconnected, all nets connected; schematic C3/C5 footprint synced.
    - Enlarged 40x45 -> 50x45 (within the <=50x50 budget); relocated P1 + MH2/MH3
    to the new right edge (rest of the board untouched).
    - Added CAP-SMD_BD10.0 to simplefocmini.pretty (from the easyeda2kicad download);
    swapped C3/C5 footprints (pad nets re-bound by name).
    - Placed both cans rot90, stacked on th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
    [project.kicad_pcb, project.kicad_sch]
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2026-06-17 Silk: rebrand SimpleFOC Mini -> DRV8313
    Renamed the PCB silkscreen branding (top + bottom) from 'SimpleFOC Mini v2.0' to 'DRV8313', updated the doc URL to the new repo and the date; regenerated the silk gerbers, PCB SVGs, and 3D renders to match. 0 error-severity DRC, unchanged otherwise.
    [project.kicad_pcb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]
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2026-06-17 BOM: source all parts (JLCPCB Basic-preferred) + 3D models so all parts render
    BOM (manufacturing/drv8313-board-BOM.csv) - fill every blank MPN/LCSC and fix
    two import-era errors:
    - R1-R4 carried the 4.7k part C23162 despite a 10k value -> C25804 (Basic)
    - P1's C146243 was actually a 3-pin header, not the 5-pos block -> DB126V-5.0-5P (C2835160)
    Filled: R6/R7/R12 10k C25804, R9 43k C23172, R10 62k C23221, R11 1k C21190,
    R8 50mOhm 3W shunt C2903475, C6 470nF C1623 (= C4), H1 2x7 socket C38844,
    TB_PWR1 2-pos block C395849. Values normalized so identical parts group;
    PCB value text synced to match.
    3D render - the project-local footprints referenced 3D models in directories
    that were never comm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
    [C0603_L1.6-W0.8-H0.8.step, CAP-SMD_BD10.0-L10.3-W10.3-FD-LS11.0.step, CONN-TH_5P-P5.00-L8.0-W25.0.step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]
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2026-06-18 PCB: edge-facing connector labels, TB_PWR1 GND/VM, top-down/front-view renders
    - Flip TB_PWR1 180 so the wire openings face the board edge (re-route VCC, swap pads)
    - Relabel TB_PWR1 +/- to GND/VM on the openings side; drop the redundant back-silk
    8-60V and add one next to the terminal
    - Orient connector labels to face their nearest edge so wire-inserters read them
    upright: H1 180, P1 (right) 90, TB_PWR1 (left) 270
    - Move P1 motor labels (VM/M3/M2/M1/GND) out from under the block to the openings
    - Renders: straight top-down/bottom-up 3D; 2D plots on a dark background; bottom
    plotted front/look-through (no --mirror) so it overlays the top for comparison
    - Regenerate gerbers/CPL/STEP/ima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
    [drv8313-board-CPL.csv, project-BottomLayer.gbl, project-BottomSilkLayer.gbo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]
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2026-06-18 Strip EasyEDA decoration zones; restore footprint silk
    Remove 131 stray EasyEDA-import decoration zones (component/lead-shape/paste-region shapes left at absolute board coordinates) from the board and the 6 project-library footprints. They rendered ~150mm from their pads in the editor and were cosmetic only (on user/doc layers; never reached the fab gerbers).
    Restore footprint body silk on C4/C3/C5/H1 so each matches its library copy, driving lib_footprint_mismatch 4->0 and keeping footprint_symbol_field_mismatch at 0 -- trading those investigate-required parity warnings for self-evidently-safe silk_over_copper/silk_overlap (fabs auto-clip silk off pads). C4 (C0603, arc silk) was replaced w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
    [project.kicad_pcb]
2026-06-18 Add VM decoupling caps (C7/C8); delete planning docs; reconcile docs
    Datasheet conformance: the DRV8313 VM pin spec calls for two 0.1 uF
    VM->GND ceramics (one per VM pin) in addition to the bulk cap; the board
    had bulk only. Added C7/C8 = 100nF/100V 0603 (Samsung CL10B104KC8NNNC /
    LCSC C15725), each wired VCC(VM)<->GND (netlist-verified one pin per net).
    PCB placement at U1 pins 4 & 11 + routing still pending.
    Docs: deleted the now-complete redesign-plan.html / redesign-bom.md
    planning docs and fixed the references/inconsistencies they left behind:
    - README: docs/ row trimmed to datasheets; status now "DRC-clean (0 errors)"
    with ERC items called out as EasyEDA-import artifacts (not real e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
    [project.kicad_sch]
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2026-06-26 Review manual layout; add power/GND/thermal improvements
    Schematic: graphical-only relayout (R8/PGND-label moved, redundant GND
    symbol added) — netlist verified byte-identical to prior commit; ERC 101->98.
    PCB fixes & improvements:
    - Re-ground U1's 8 EP thermal vias (Update-from-Schematic had stripped GND)
    and rename them to pad "29" so they survive every future sync.
    - Add Power net class (0.6mm) for VCC/M1/M2/M3/PGND; widen the current-
    carrying runs 0.2->0.6mm with neck-down kept at the HTSSOP escape.
    - Add F.Cu + B.Cu GND pours + 38 stitching vias (datasheet 10.1; lowers
    RthJA, better return paths/EMI).
    - Extend EP thermal-via array 8->12 (6x2); add GND-return vias at the C7/C8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
    [project.kicad_pcb, project.kicad_sch]
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2026-06-28 Swap simple passives to KiCad Device symbols; clear all ERC errors
    Per user direction, move the simple passives off the EasyEDA-imported symbols
    onto KiCad library symbols, and fix the schematic so ERC has zero errors.
    - R1-R12 -> Device:R, ceramics -> Device:C, electrolytics C3/C5 ->
    Device:C_Polarized, SJ1/SJ2 -> Jumper:SolderJumper_2_Bridged. Removed the 9
    now-unused old EasyEDA passive lib_symbols. Kept U1 (no KiCad equivalent),
    H1/P1 (already generic), TB_PWR1.
    - LED1 kept on its symbol (Device:LED numbers pin1=K, conflicting with the
    verified PCB pad1=anode) but its pins retyped input->passive.
    - Added PWR_FLAG on VCC/GND/3.3V and a no-connect on U1.21.
    Net-preserving: verifi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
    [project.kicad_sch]
2026-06-28 Relink power symbols to KiCad power lib + type U1 pins; ERC warnings 53->8
    Follow-up to the Device-symbol swap, clearing most remaining ERC warnings.
    - Relinked GND/VCC/3.3V power symbols to the KiCad power library
    (power:GND / power:VCC / power:+3.3V). A power symbol's net name comes from
    its instance Value field, so the 3.3V instances keep Value 3.3V and the net
    stays 3.3V (no PCB net rename) -- verified by netlist.
    - Typed U1's pins: power_in (VM/GND/EP), power_out (V3P3OUT), output (OUT1-3),
    open_collector (nFAULT/nCOMPO), passive (rest). Left IN/EN/nRESET/nSLEEP/
    COMPP/COMPN as passive on purpose -- their drivers are passive (header +
    pull-ups + shunt), so typing them input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
    [project.kicad_sch]
2026-06-28 ERC fully clean (0): project symbol lib for U1/LED1, TB_PWR1 -> Conn_01x02
    Final cleanup taking ERC from 8 warnings to 0.
    - U1 (DRV8313PWPR) and LED1's symbol have no KiCad-standard equivalent, so
    added a project symbol library KiCad/project/simplefocmini.kicad_sym + a
    project sym-lib-table, renamed the cache entries to simplefocmini:<name>, and
    relinked the instances. kicad-cli sch erc reads the project sym-lib-table
    (KIPRJMOD), so these now resolve -> 2 lib_symbol_issues cleared.
    - TB_PWR1: swapped the custom TB002-500-02BE symbol to the stock
    Connector_Generic:Conn_01x02 (consistent with P1=Conn_01x05 / H1=Conn_02x07),
    and rebuilt the cluster on-grid with the GND/VCC power sy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
    [project.kicad_sch]
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2026-07-03 Rework
    Remove resistors on enable lines.
    Redo board layout with clearer and wider power paths.
    [project.kicad_pcb, project.kicad_sch]
2026-07-03 Fix starved thermal on U1 pad 4 (VM): solid zone connection
    DRC flagged starved_thermal on pad 4 -- at the 0.65mm HTSSOP pitch the
    VCC pour can only reach the pad from one side, so a thermal relief gets
    1 spoke (min 2). A solid (no-relief) connection clears the error and is
    electrically better for a power pin feeding its own pour. Zones
    refilled; check_design.py now PASSes (DRC 0, ERC 0).
    [project.kicad_pcb]
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
